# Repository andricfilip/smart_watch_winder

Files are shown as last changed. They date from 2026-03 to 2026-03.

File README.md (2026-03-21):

# Watch Winder - Full Project Guide

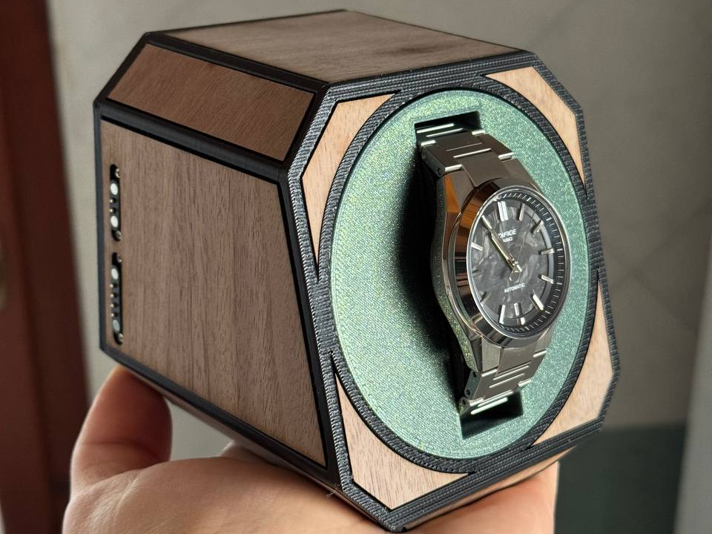
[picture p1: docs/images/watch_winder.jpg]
Watch Winder


This repository contains the complete watch-winder solution:

1. ESP8266 firmware for one watch (`winder/winder.ino`)
2. ESP8266 firmware for two watches (`doubleWinder/doubleWinder.ino`)
3. Raspberry Pi web dashboard (`pi-dashboard/`)
4. Modern React dashboard (`pi-dashboard-modern/`)
5. Assembly docs (SR + EN) in `docs/`

The firmware is API-only (no embedded HTML UI), and the dashboard controls the device over HTTP.

## 1) Project Structure

- `winder/winder.ino` - single watch firmware
- `doubleWinder/doubleWinder.ino` - double watch firmware
- `pi-dashboard/index.html` - dashboard UI
- `pi-dashboard/app.js` - dashboard logic and API calls
- `pi-dashboard/style.css` - dashboard style
- `pi-dashboard/docker-compose.yml` - dashboard container deploy
- `pi-dashboard-modern/` - modern React + Vite dashboard
- `docs/ASSEMBLY_GUIDE_SR.md` - assembly guide in Serbian
- `docs/ASSEMBLY_GUIDE_EN.md` - assembly guide in English
- `docs/images/` - wiring images used in docs
- `docs/images/watch_winder.jpg` - project preview image

## Assembly Guides

- Serbian: [docs/ASSEMBLY_GUIDE_SR.md](docs/ASSEMBLY_GUIDE_SR.md)
- English: [docs/ASSEMBLY_GUIDE_EN.md](docs/ASSEMBLY_GUIDE_EN.md)

## 2) How The System Works

1. ESP8266 runs motor control and exposes HTTP API.
2. Raspberry Pi hosts the dashboard.
3. Browser dashboard sends commands directly to ESP8266 API.
4. Internet is not required.
5. Local network path between browser and ESP8266 is required.

## 3) Choose Firmware (Single vs Double)

Flash only one firmware on one ESP8266 board:

- Use `winder/winder.ino` for one watch.
- Use `doubleWinder/doubleWinder.ino` for two watches.

## 4) Firmware Configuration (Required)

Before flashing, edit these constants in the selected `.ino` file:

- `STA_SSID`
- `STA_PASSWORD`
- `ENABLE_AP_FALLBACK`
- `AP_SSID`
- `AP_PASSWORD`
- `STA_CONNECT_TIMEOUT_MS`

Recommended values:

- `ENABLE_AP_FALLBACK = true` while testing
- `AP_PASSWORD` at least 12 characters
- `STA_CONNECT_TIMEOUT_MS = 10000` to `20000`

What they mean:

- `STA_*` = your home/local Wi-Fi credentials
- `ENABLE_AP_FALLBACK`:
  - `true` -> if STA connection fails, ESP starts fallback AP
  - `false` -> no AP fallback, ESP stays without network if STA fails
- `AP_*` = fallback network name/password

## 5) Runtime Config Parameters (TPD Engine)

The firmware now uses a time-based TPD scheduler instead of fixed `giri/delay` loops.

### Core parameters

- `targetTPD` range: `500-1000` (hard cap)
- `direction`: `CW`, `CCW`, `BIDIR`
- `mode`: `STANDARD`, `SMART`
- `speed` range: `1-5`
- `activeHours`: `[startHour, endHour]` (0-23)
- `runMinutes` range: `0-1440`

### Optional quiet profile

- `quietMode`: `true/false`
- `quietStartHour`, `quietEndHour`
- `nightSpeedCap`

Timer behavior:

- `runMinutes = 0` -> unlimited run time
- `runMinutes > 0` -> auto-stop after timer expires

## 6) API Endpoints

Available in both firmware variants:

- `GET /api/status`
- `GET /api/stats`
- `GET /api/health`
- `POST /api/config`
- `POST /api/start`
- `POST /api/stop`

Notes:

- Config write is POST-only.
- `POST /api/stop` is fail-safe and immediately releases motor outputs.
- Legacy `giri/delay` keys are still accepted for backward compatibility.

### Example `/api/config` payload

```json
{
  "targetTPD": 650,
  "direction": "BIDIR",
  "mode": "SMART",
  "speed": 3,
  "activeHours": [8, 23],
  "runMinutes": 0,
  "quietMode": true,
  "quietStartHour": 22,
  "quietEndHour": 7,
  "nightSpeedCap": 2
}
```

## 7) EEPROM Safety

Both firmware variants use protected config storage:

- magic
- version
- CRC

This prevents invalid config loads when format changes or EEPROM data is corrupted.

## 8) Stability Enhancements In Firmware

Both firmware variants include:

- non-blocking `millis()` scheduler (Wi-Fi friendly)
- rolling 24h progress tracking with hourly drift correction
- adaptive burst/pause distribution based on drift percent
- soft start/stop step ramp to reduce vibration/noise
- state machine: `IDLE`, `RUNNING`, `PAUSED`, `ERROR`, `TIMER_DONE`
- robust persistence with versioned records, CRC, and dual-slot write strategy
- periodic runtime snapshot for power-loss recovery

New runtime metrics exposed via API:

- `rotationsToday`
- `rotationsLastHour`
- `currentTPD`
- `driftPercent`
- `currentTPDProgress`
- `remainingRotations`
- `errorCode`

## 9) Flashing ESP8266

Use Arduino IDE or PlatformIO.

Basic Arduino IDE flow:

1. Open selected `.ino`.
2. Select correct ESP8266 board and COM port.
3. Install required libraries if missing (`ESP8266WiFi`, `ESP8266WebServer`, `EEPROM`).
4. Verify/Compile.
5. Upload.
6. Open Serial Monitor (115200) and read assigned IP.

## 10) Dashboard Setup On Raspberry Pi

### Option A - Simple static server

```bash
cd pi-dashboard
python3 -m http.server 8080
```

Open:

- Local Pi browser: `http://localhost:8080`
- Other LAN devices: `http://<IP_RASPBERRY_PI>:8080`

### Option B - Docker

```bash
cd pi-dashboard
docker compose up -d --build
```

Open from LAN devices:

- `http://<IP_RASPBERRY_PI>:8080`

Stop:

```bash
docker compose down
```

## 11) Dashboard First Start

1. Open dashboard.
2. Enter ESP URL (default example: `http://192.168.1.111`).
3. Choose mode:
   - `Single winder (1 sat)`
   - `Double winder (2 sata)`
4. Save device.
5. Click `Osvezi status`.
6. Configure values.
7. Click `Start`.
8. Use `Stop` when needed.

## 12) Network Scenarios

### Scenario A: Home Wi-Fi works

- ESP connects as STA.
- Dashboard (Pi/phone/laptop) reaches ESP via local IP.

### Scenario B: Home Wi-Fi fails + fallback enabled

- ESP starts fallback AP.
- Connect client device to AP.
- Dashboard works over fallback AP network.

### Scenario C: Home Wi-Fi fails + fallback disabled

- ESP is unreachable over network.
- Dashboard UI opens, but API calls fail.

## 13) Security Notes

- Keep strong `AP_PASSWORD` if fallback is enabled.
- Do not expose dashboard to internet unless you add auth/reverse proxy hardening.
- If you want LAN-only access, do not configure router port forwarding for `8080`.

## 14) Quick Troubleshooting

If dashboard shows offline / fetch errors:

1. Verify ESP and dashboard client are on reachable networks.
2. Confirm ESP IP in dashboard URL field.
3. Open `http://<ESP_IP>/api/status` directly from browser.
4. Check Serial Monitor for STA success/failure and fallback AP startup.
5. If browser cached old URL, save the new URL in dashboard again.

## 15) Recommended Production Profile

1. Validate stable STA connection for several reboots.
2. Keep fallback AP enabled only if you need service recovery.
3. Set sensible timer and speed values for your watch movement.
4. Periodically inspect `cyclesCompleted` and `lastStopReason` from `/api/status`.

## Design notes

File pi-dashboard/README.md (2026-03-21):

# Kontrola navijanja automatskog sata

Ovaj projekat ima dva firmware fajla i jedan dashboard:

1. `winder/winder.ino` za jedan sat.
2. `doubleWinder/doubleWinder.ino` za dva sata.
3. `pi-dashboard/` web panel za upravljanje i telemetriju.

## API endpointi

- `GET /api/status`
- `GET /api/stats`
- `GET /api/health`
- `POST /api/config`
- `POST /api/start`
- `POST /api/stop`

## Sta da menjas u firmware fajlovima

U oba fajla menjas iste mrezne konstante na vrhu:

1. `STA_SSID`: naziv tvoje kućne Wi-Fi mreze.
2. `STA_PASSWORD`: lozinka tvoje kućne mreze.
3. `ENABLE_AP_FALLBACK`: `true` ili `false`.
4. `AP_SSID`: naziv fallback AP mreze.
5. `AP_PASSWORD`: lozinka fallback AP mreze.
6. `STA_CONNECT_TIMEOUT_MS`: vreme cekanja konekcije na Wi-Fi.

Preporucene vrednosti:

1. `ENABLE_AP_FALLBACK = true` dok testiras.
2. `AP_PASSWORD` promeni u jaku lozinku od bar 12 karaktera.
3. `STA_CONNECT_TIMEOUT_MS = 10000` do `20000`.

## Razlika single i double firmware-a (TPD engine)

Single (`winder/winder.ino`) glavni parametri:

1. `targetTPD` opseg `500-1000`.
2. `direction`: `CW`, `CCW`, `BIDIR`.
3. `mode`: `STANDARD` ili `SMART`.
4. `speed` opseg `1-5`.
5. `activeHours`: `[startHour, endHour]`.
6. `runMinutes` opseg `0-1440`.

Double (`doubleWinder/doubleWinder.ino`) glavni parametri:

1. `targetTPD1`, `targetTPD2` opseg `500-1000`.
2. `direction1`, `direction2`.
3. `mode1`, `mode2`.
4. `speed1`, `speed2` opseg `1-5`.
5. `activeStartHour1/2`, `activeEndHour1/2`.
6. `runMinutes` opseg `0-1440`.

Napomena:

1. Legacy polja (`giri`, `delay`, `giri1`, `giri2`, `gdelay`) su i dalje podrzana radi kompatibilnosti.
2. Dashboard sada salje nova TPD polja kao JSON.

## Podrazumevano ponasanje tajmera

1. `runMinutes = 0` znaci rad bez vremenskog limita.
2. `POST /api/start` pokrece sistem.
3. Ako je `runMinutes > 0`, sistem se sam zaustavlja po isteku vremena.
4. `POST /api/stop` odmah zaustavlja sve motore (fail-safe stop).

## Nova telemetrija u statusu

`/api/status`, `/api/stats` i `/api/health` sada vracaju dodatne metrike:

1. `rotationsToday`
2. `rotationsLastHour`
3. `currentTPD`
4. `driftPercent`
5. `currentTPDProgress`
6. `remainingRotations`
7. `motorState`
8. `errorCode`
9. `uptime`

## Pokretanje dashboard-a

Lokalno na Raspberry Pi:

```bash
cd pi-dashboard
python3 -m http.server 8080
```

Dashboard URL:

```text
http://localhost:8080
```

## Docker deploy za lokalnu mrezu

```bash
cd pi-dashboard
docker compose up -d --build
```

Otvaranje sa drugih uredjaja u istoj mrezi:

```text
http://IP_RASPBERRY_PI:8080
```

Gasenje:

```bash
docker compose down
```

Napomena:

1. Nemoj raditi port forwarding na ruteru za port `8080` ako zelis samo LAN pristup.
2. Dashboard podrazumevano koristi URL `http://192.168.1.111`, ali ga mozes promeniti u panelu.

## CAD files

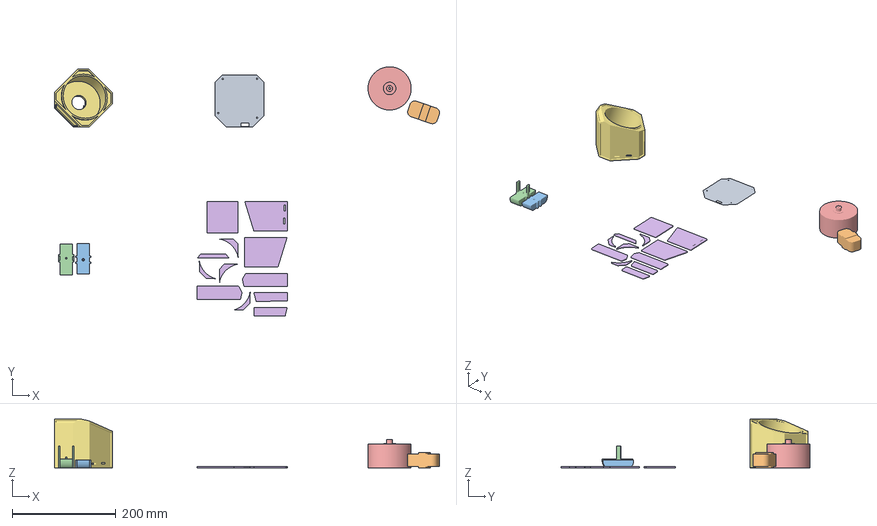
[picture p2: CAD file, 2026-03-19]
print_profile/BackSmall.3mf
743.3 x 481.3 x 94.5 mm
BackSmall.stl
RotorSmall.stl_2
WatchHolderV2.stl
Sub-merged body
RotorSmall.stl
BodyPanels.stl
BodySmall.stl

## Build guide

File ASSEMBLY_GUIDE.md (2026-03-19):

# Assembly Guide Index

Assembly documentation has been moved to the docs folder.

- Serbian version: [docs/ASSEMBLY_GUIDE_SR.md](docs/ASSEMBLY_GUIDE_SR.md)
- English version: [docs/ASSEMBLY_GUIDE_EN.md](docs/ASSEMBLY_GUIDE_EN.md)

Wiring images used by both guides:

- [docs/images/single-wiring.png](docs/images/single-wiring.png)
- [docs/images/double-wiring.png](docs/images/double-wiring.png)

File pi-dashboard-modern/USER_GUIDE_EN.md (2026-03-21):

# Application User Guide (Modern Dashboard)

This is a practical guide: what to configure, which values to use, and what result you get on your watch winder.

## 1. What this app does

The app controls ESP8266 firmware over local network.

Supported:

1. start and stop winding
2. TPD-based configuration
3. direction and mode selection
4. runtime and health telemetry

## 2. Quick start (3 minutes)

1. Make sure firmware is uploaded to ESP:
   - single: `winder/winder.ino`
   - double: `doubleWinder/doubleWinder.ino`
2. Start dashboard:
   - `cd pi-dashboard-modern`
   - `docker compose up --build -d`
3. Open in browser: `http://IP_RPI:8090` (or `http://localhost:8090` on Raspberry Pi)
4. Click `Refresh`.
5. Set parameters and click `Save settings`.
6. Click `Start`.

If status is `Offline`, verify ESP and dashboard are on same network and device URL is correct.

## 3. Parameters and expected behavior

## targetTPD (500-1000)

Meaning:

- number of target rotations in 24h

Effect:

- higher TPD = more frequent activity and more total rotations
- lower TPD = less frequent activity and quieter operation

Recommendation:

- start with `650`, then fine tune for your watch

## direction (CW / CCW / BIDIR)

Meaning:

- winding direction

Effect:

- `CW`: clockwise only
- `CCW`: counterclockwise only
- `BIDIR`: alternating direction (safe default if watch requirement is unknown)

## mode (STANDARD / SMART)

Meaning:

- cycle distribution strategy

Effect:

- `STANDARD`: regular distribution through the day
- `SMART`: adaptive balancing of winding cycles

## speed (1-5)

Meaning:

- stepper speed level

Effect:

- `1-2`: quieter and smoother
- `4-5`: faster execution, potentially more noise

Recommendation:

- use `2` or `3` for stable and quiet behavior

## activeHours

Meaning:

- time window when winding is allowed

Effect:

- outside this range, system pauses

Example:

- `8-23`: active during day/evening, idle at night

## smartSwitchRotations

Meaning:

- in SMART mode, direction switch interval in rotations

Effect:

- higher value = less frequent direction changes
- lower value = more frequent direction changes

## quietMode + quietStartHour + quietEndHour + nightSpeedCap

Meaning:

- quieter night profile

Effect:

- in quiet hours speed is limited by `nightSpeedCap`
- less noise during night

Example:

- quiet from `22` to `7`, cap `2`

## runMinutes

Meaning:

- max runtime before auto-stop

Effect:

- `0` = no time limit
- `>0` = auto-stop after configured duration

## 4. Status panel metrics

1. `State`: current state (`IDLE`, `RUNNING`, `PAUSED`, `ERROR`, `TIMER_DONE`)
2. `Error`: error code if present
3. `Timer`: remaining timer time
4. `Network`: network mode and IP
5. `Rot today`: total rotations today
6. `Rot hour`: rotations in last hour
7. `Current TPD`: projected current TPD pace
8. `Drift %`: deviation from planned daily pace
9. `Progress`: completion percent for daily target
10. `Remaining`: rotations left to target
11. `Heap`: free ESP memory
12. `Uptime`: device uptime

## 5. Recommended starting values

### Single

1. targetTPD: `650`
2. direction: `BIDIR`
3. mode: `STANDARD`
4. speed: `2`
5. activeHours: `0-23`
6. quietMode: `true`
7. quiet: `22-7`, cap `2`

### Double

1. targetTPD1/2: `650`
2. direction1/2: `BIDIR`
3. mode1/2: `STANDARD`
4. speed1/2: `2`
5. active hours for both heads: `0-23`
6. quietMode: `true`

## 6. Single vs Double

1. If firmware is single, use single settings.
2. If firmware is double, use double settings.
3. If mode lock is enabled via Docker env, app mode cannot be changed from UI.

## 7. Common situations and fixes

## Offline

1. Check `APP_DEFAULT_DEVICE_URL` in `docker-compose.yml`.
2. Verify ESP responds to `GET /api/status` from browser.
3. Confirm ESP and dashboard are on same LAN.

## Motor is too noisy

1. lower `speed` to `2`
2. enable `quietMode`
3. set `nightSpeedCap` to `1` or `2`

## Watch seems under-wound

1. increase `targetTPD` in +50 steps
2. monitor `Drift %` and `Remaining`

## 8. Docker startup config (important)

In `pi-dashboard-modern/docker-compose.yml` use:

1. `APP_DEVICE_MODE`: `single` or `double`
2. `APP_LOCK_DEVICE_MODE`: lock mode in UI
3. `APP_DEFAULT_DEVICE_URL`: ESP IP address
4. `APP_LOCK_DEVICE_URL`: lock URL field
5. `APP_LANGUAGE`: `sr` or `en`
6. `APP_LOCK_LANGUAGE`: lock language selection

After changing env values, run:

1. `docker compose up --build -d`

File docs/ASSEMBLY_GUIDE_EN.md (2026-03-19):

# Watch Winder Assembly Guide

This is a compact watch winder build with wooden slots (3D printable panels) and optional Pogo pin contacts for a modular second winder.

## 1. Quick Overview

The system uses:

1. D1 Mini (ESP8266)
2. 28BYJ-48 stepper + ULN2003 driver
3. Bearings and 3D printed parts
4. Optional Pogo pins for the second modular motor

If the motor does not rotate correctly (vibration, stuttering, unstable direction), the 4 signal wires between D1 Mini and ULN2003 may require a different order depending on motor batch. Reorder the 4 signal wires until rotation is smooth.

## 2. Bill of Materials (BOM)

1. Pogo pins (4P + 2P pair)
   https://s.click.aliexpress.com/e/_c2xJoAxh
2. D1 Mini microcontroller
   https://s.click.aliexpress.com/e/_c2yz2bsB
3. Stepper motor + ULN2003 driver (one set per winder)
   https://s.click.aliexpress.com/e/_c3bp08OR
4. 6001ZZ bearings
   https://s.click.aliexpress.com/e/_c3FSeHun

Notes:

- Single variant needs 1x motor + driver.
- Double variant needs 2x motor + driver.
- Pogo pins are optional, but recommended for modular second-winder contacts.

## 3. Wiring Diagrams (Single and Double)

### Single winder wiring

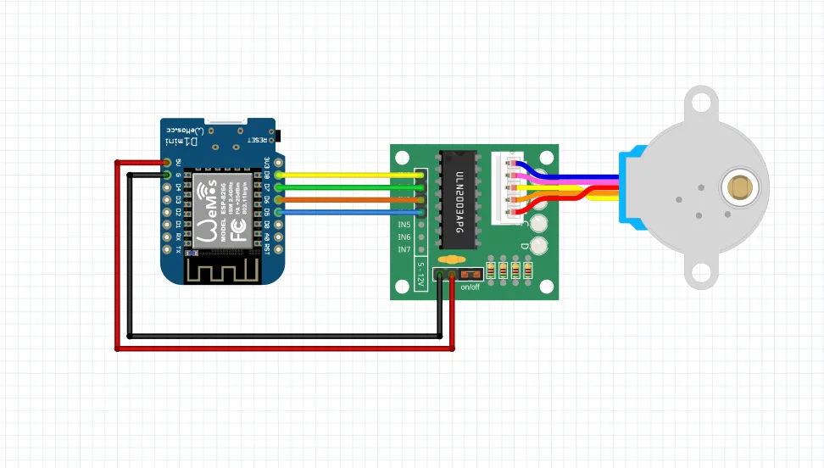
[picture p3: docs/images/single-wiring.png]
Single winder wiring


### Double winder wiring

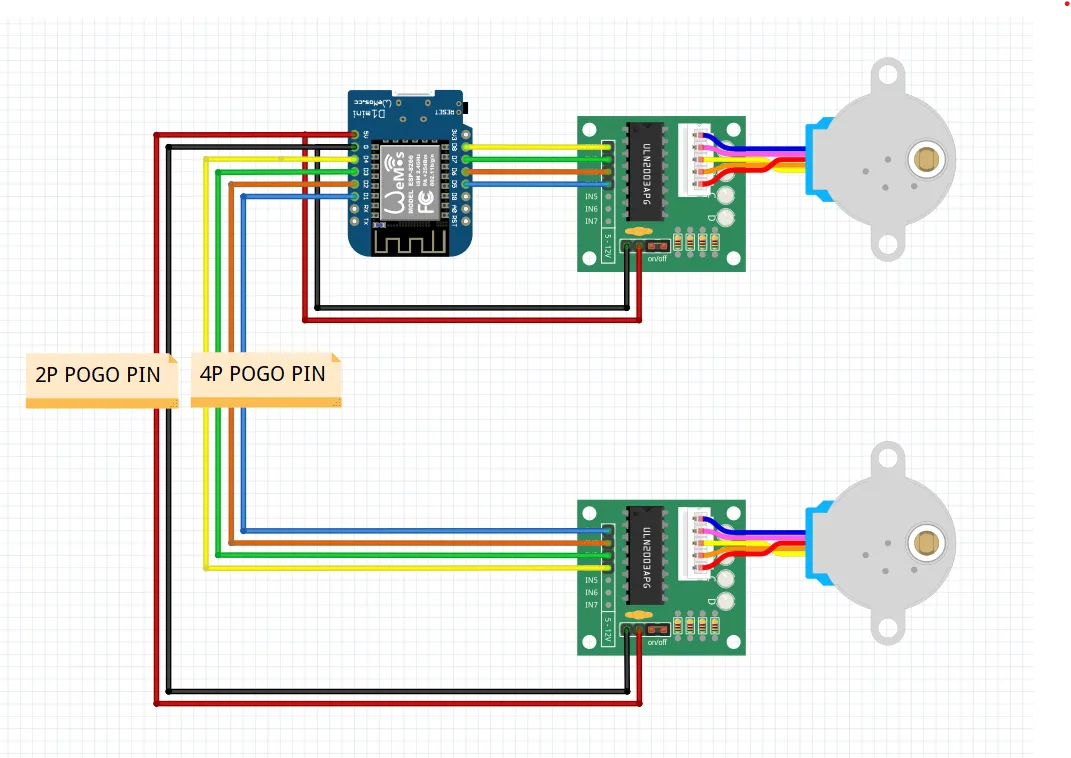
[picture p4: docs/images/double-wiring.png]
Double winder wiring


## 4. Pin Mapping (Firmware)

### Single firmware

File: `winder/winder.ino`

- `IN1 = D5`
- `IN2 = D6`
- `IN3 = D7`
- `IN4 = D8`

### Double firmware

File: `doubleWinder/doubleWinder.ino`

Motor A:

- `IN1_A = D5`
- `IN2_A = D6`
- `IN3_A = D7`
- `IN4_A = D8`

Motor B:

- `IN1_B = D4`
- `IN2_B = D3`
- `IN3_B = D2`
- `IN4_B = D1`

## 5. Step-by-Step Assembly

1. Assemble the mechanical structure and install 6001ZZ bearings.
2. Mount D1 Mini and ULN2003 driver board(s).
3. Connect shared power and GND for all modules.
4. Connect D1 Mini signal wires to ULN2003 according to pin map.
5. Connect the stepper cable to ULN2003.
6. For double variant, wire the second driver/motor pair.
7. If using Pogo pins, verify both 4P (signal) and 2P (power/GND) contact quality.
8. Before closing the case, test rotation at low speed.

## 6. Firmware Selection and Upload

1. For one watch, upload `winder/winder.ino`.
2. For two watches, upload `doubleWinder/doubleWinder.ino`.

Before uploading, configure network constants in firmware:

- `STA_SSID`
- `STA_PASSWORD`
- `ENABLE_AP_FALLBACK`
- `AP_SSID`
- `AP_PASSWORD`
- `STA_CONNECT_TIMEOUT_MS`

Recommended settings:

1. Keep `ENABLE_AP_FALLBACK = true` during initial testing.
2. Use a strong `AP_PASSWORD` (12+ chars).
3. Set `STA_CONNECT_TIMEOUT_MS` to 10000-20000.

## 7. First Boot and Validation

1. Upload firmware.
2. Open Serial Monitor at 115200 and read the assigned IP.
3. Start dashboard from folder `pi-dashboard`.
4. In dashboard, set device URL and click Save Device.
5. Click Refresh Status.
6. Configure parameters and click Start.
7. Verify direction and smooth rotation.

## 8. Dashboard and Timer

- `runMinutes = 0`: unlimited run.
- `runMinutes > 0`: automatic stop when timer expires.
- `Stop` is fail-safe and immediately releases the motor.

## 9. Recommended Starting Setup

Single:

1. `giri = 3`
2. `speed = 2`
3. `delay = 7`

Double:

1. `giri1 = 3`, `speed1 = 2`
2. `giri2 = 3`, `speed2 = 2`
3. `gdelay = 7`

Then fine-tune values based on watch weight and mechanical fit.

## 10. Troubleshooting

1. Motor does not start:
   - check power and shared GND
   - check motor connector on ULN2003
2. Motor vibrates but does not rotate:
   - reorder the 4 signal wires
3. Dashboard reports offline:
   - confirm IP and make sure ESP and dashboard are on same LAN
4. Second motor not working in double mode:
   - verify Motor B pin mapping
   - inspect 2P/4P Pogo contacts

## 11. Video References

Add links to your published videos:

- Part 1: <INSERT_LINK>
- Part 2: <INSERT_LINK>
- Final version: <INSERT_LINK>

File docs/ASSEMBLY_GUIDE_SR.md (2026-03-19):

# Watch Winder Uputstvo za Sklapanje

Elegant watch winder sa drvenim slotovima (3D printable paneli).
Ovo je novi, kompaktniji model sa opcijom Pogo pin kontakata za drugi winder.

## 1. Kratak pregled

Sistem koristi:

1. D1 Mini (ESP8266)
2. 28BYJ-48 stepper + ULN2003 driver
3. lezajeve i 3D print delove
4. opciono Pogo pinove za modularni drugi motor

Ako motor ne radi pravilno (vibrira, preskace, menja smer cudno), redosled 4 signalna voda izmedju D1 Mini i ULN2003 moze da varira u zavisnosti od motora. Menjaj redosled dok ne dobijes stabilnu rotaciju.

## 2. Materijal (BOM)

1. Pogo pins (4P + 2P par)
   https://s.click.aliexpress.com/e/_c2xJoAxh
2. D1 Mini microcontroller
   https://s.click.aliexpress.com/e/_c2yz2bsB
3. Stepper motor + ULN2003 driver (za svaki winder po 1 set)
   https://s.click.aliexpress.com/e/_c3bp08OR
4. 6001ZZ bearings
   https://s.click.aliexpress.com/e/_c3FSeHun

Napomena:

- Za single varijantu treba 1x motor+driver.
- Za double varijantu trebaju 2x motor+driver.
- Pogo pinovi su opcioni, ali preporuceni za modularni drugi winder.

## 3. Vizuelno povezivanje (single i double)

### Single winder wiring

Single winder wiring

### Double winder wiring

Double winder wiring

## 4. Pin mapping (firmware)

### Single firmware

Fajl: `winder/winder.ino`

- `IN1 = D5`
- `IN2 = D6`
- `IN3 = D7`
- `IN4 = D8`

### Double firmware

Fajl: `doubleWinder/doubleWinder.ino`

Motor A:

- `IN1_A = D5`
- `IN2_A = D6`
- `IN3_A = D7`
- `IN4_A = D8`

Motor B:

- `IN1_B = D4`
- `IN2_B = D3`
- `IN3_B = D2`
- `IN4_B = D1`

## 5. Korak-po-korak sklapanje

1. Sastavi mehanicki deo i ubaci 6001ZZ lezajeve.
2. Montiraj D1 Mini i ULN2003 driver(e) na nosace.
3. Povezi napajanje i GND zajednicki za sve module.
4. Povezi signalne vodove sa D1 Mini na ULN2003 prema pin mapiranju.
5. Povezi stepper konektor na ULN2003.
6. Ako koristis double varijantu, povezi i drugi driver.
7. Ako koristis Pogo pinove, proveri kontakt 4P (signal) i 2P (napajanje/GND).
8. Pre prvog zatvaranja kucista testiraj rotaciju sa malom brzinom.

## 6. Firmware izbor i upload

1. Za 1 sat upload `winder/winder.ino`.
2. Za 2 sata upload `doubleWinder/doubleWinder.ino`.

Pre upload-a podesi mrezu u firmware-u:

- `STA_SSID`
- `STA_PASSWORD`
- `ENABLE_AP_FALLBACK`
- `AP_SSID`
- `AP_PASSWORD`
- `STA_CONNECT_TIMEOUT_MS`

Preporuka:

1. Drzi `ENABLE_AP_FALLBACK = true` dok testiras.
2. Koristi jaku `AP_PASSWORD` lozinku (12+ karaktera).
3. `STA_CONNECT_TIMEOUT_MS` stavi 10000-20000.

## 7. Prvo pokretanje i test

1. Uploadaj firmware.
2. Otvori Serial Monitor na 115200 i procitaj IP adresu.
3. Pokreni dashboard iz foldera `pi-dashboard`.
4. U dashboard unesi URL uredjaja i klikni `Sacuvaj uredjaj`.
5. Klikni `Osvezi status`.
6. Podesi parametre i `Start`.
7. Proveri smer i stabilnost okretanja.

## 8. Dashboard i tajmer

- `runMinutes = 0`: bez limita rada.
- `runMinutes > 0`: automatski stop po isteku vremena.
- `Stop` je fail-safe i odmah otpusta motor.

## 9. Recommended starting setup

Single:

1. `giri = 3`
2. `speed = 2`
3. `delay = 7`

Double:

1. `giri1 = 3`, `speed1 = 2`
2. `giri2 = 3`, `speed2 = 2`
3. `gdelay = 7`

Zatim fino podesi u odnosu na sat i mehaniku nosaca.

## 10. Troubleshooting

1. Motor ne krece:
   - proveri napajanje i GND
   - proveri konektor motora na ULN2003
2. Motor vibrira bez rotacije:
   - promeni redosled 4 signalna voda
3. Dashboard je offline:
   - proveri IP i da su ESP i dashboard u istoj mrezi
4. Double ne radi na drugom motoru:
   - proveri pin mapiranje za Motor B
   - proveri 2P/4P Pogo kontakte

## 11. Video reference

Dodaj linkove ka svojim objavama:

- Part 1: <INSERT_LINK>
- Part 2: <INSERT_LINK>
- Final version: <INSERT_LINK>

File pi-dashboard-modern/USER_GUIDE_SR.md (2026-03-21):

# Uputstvo za koriscenje aplikacije (Modern Dashboard)

Ovo je prakticno uputstvo: sta da podesis, koje vrednosti da uneses i kakav rezultat dobijas na watch winder uredjaju.

## 1. Sta aplikacija radi

Aplikacija upravlja ESP8266 firmware-om preko lokalne mreze.

Podrzano:

1. pokretanje i zaustavljanje navijanja
2. podesavanje TPD logike
3. izbor smera i rezima rada
4. pracenje metrike rada i zdravlja sistema

## 2. Brzi start (3 minuta)

1. Uveri se da je firmware uploadovan na ESP:
   - single: `winder/winder.ino`
   - double: `doubleWinder/doubleWinder.ino`
2. Pokreni dashboard:
   - `cd pi-dashboard-modern`
   - `docker compose up --build -d`
3. Otvori u browser-u: `http://IP_RPI:8090` (ili `http://localhost:8090` na samom Pi)
4. Klikni `Osvezi`.
5. Podesi parametre i klikni `Sacuvaj podesavanja`.
6. Klikni `Start`.

Ako je status `Van mreze`, proveri da su ESP i dashboard u istoj mrezi i da je URL tacan.

## 3. Parametri i sta dobijas

## targetTPD (500-1000)

Znacenje:

- broj rotacija koje zelis u okviru 24h

Efekat:

- veci TPD = cesce aktiviranje i vise ukupnih rotacija
- manji TPD = redje aktiviranje i mirniji rad

Preporuka:

- kreni sa `650`, pa fino podesi po ponasanju sata

## direction (CW / CCW / BIDIR)

Znacenje:

- smer navijanja

Efekat:

- `CW`: samo u smeru kazaljke
- `CCW`: samo suprotno
- `BIDIR`: naizmenicno, bezbedan izbor ako nisi siguran koji smer sat trazi

## mode (STANDARD / SMART)

Znacenje:

- nacin raspodele ciklusa

Efekat:

- `STANDARD`: regularna raspodela kroz dan
- `SMART`: inteligentnije menjanje i balansiranje ciklusa

## speed (1-5)

Znacenje:

- brzina step motora

Efekat:

- `1-2`: tisi i mirniji rad
- `4-5`: brze izvrsenje, potencijalno vise buke

Preporuka:

- koristi `2` ili `3` za stabilan i tih rad

## activeHours

Znacenje:

- satnica kada je dozvoljen aktivan rad

Efekat:

- van tog intervala sistem pauzira

Primer:

- `8-23`: radi tokom dana/veceri, miruje nocu

## smartSwitchRotations

Znacenje:

- na koliko rotacija menja smer u SMART rezimu

Efekat:

- veca vrednost = redje menjanje smera
- manja vrednost = cesce menjanje smera

## quietMode + quietStartHour + quietEndHour + nightSpeedCap

Znacenje:

- nocni tisi profil

Efekat:

- u quiet periodu brzina se limitira na `nightSpeedCap`
- manje buke nocu

Primer:

- quiet od `22` do `7`, cap `2`

## runMinutes

Znacenje:

- koliko dugo da sistem radi pre auto-stop

Efekat:

- `0` = bez limita
- `>0` = automatski stop nakon zadatog vremena

## 4. Status panel (sta znaci svaka metrika)

1. `State`: trenutno stanje (`IDLE`, `RUNNING`, `PAUSED`, `ERROR`, `TIMER_DONE`)
2. `Error`: kod greske (ako postoji)
3. `Timer`: preostalo vreme timera
4. `Network`: mrezni mod i IP
5. `Rot today`: ukupne rotacije danas
6. `Rot hour`: rotacije u poslednjem satu
7. `Current TPD`: projekcija trenutnog TPD tempa
8. `Drift %`: odstupanje od planiranog dnevnog tempa
9. `Progress`: procenat ispunjenog dnevnog plana
10. `Remaining`: preostale rotacije do cilja
11. `Heap`: slobodna memorija na ESP-u
12. `Uptime`: vreme rada uredjaja

## 5. Preporucene pocetne vrednosti

### Single

1. targetTPD: `650`
2. direction: `BIDIR`
3. mode: `STANDARD`
4. speed: `2`
5. activeHours: `0-23`
6. quietMode: `true`
7. quiet: `22-7`, cap `2`

### Double

1. targetTPD1/2: `650`
2. direction1/2: `BIDIR`
3. mode1/2: `STANDARD`
4. speed1/2: `2`
5. active hours obe glave: `0-23`
6. quietMode: `true`

## 6. Single vs Double

1. Ako je firmware single, koristi single podešavanja.
2. Ako je firmware double, koristi double podešavanja.
3. Ne treba menjati mod u aplikaciji ako je lock ukljucen kroz Docker env.

## 7. Ceste situacije i resenja

## Van mreze

1. Proveri `APP_DEFAULT_DEVICE_URL` u `docker-compose.yml`.
2. Proveri da ESP vraca `GET /api/status` iz browser-a.
3. Proveri da su uredjaji u istoj LAN mrezi.

## Motor radi preglasno

1. spusti `speed` na `2`
2. ukljuci `quietMode`
3. smanji `nightSpeedCap` na `1` ili `2`

## Sat deluje da je premalo navijan

1. povecaj `targetTPD` u koracima po 50
2. proveri `Drift %` i `Remaining`

## 8. Docker konfiguracija (najvaznije)

U `pi-dashboard-modern/docker-compose.yml` koristis:

1. `APP_DEVICE_MODE`: `single` ili `double`
2. `APP_LOCK_DEVICE_MODE`: zakljucava mod u UI
3. `APP_DEFAULT_DEVICE_URL`: IP ESP uredjaja
4. `APP_LOCK_DEVICE_URL`: zakljucava URL polje
5. `APP_LANGUAGE`: `sr` ili `en`
6. `APP_LOCK_LANGUAGE`: zakljucava izbor jezika

Posle izmene env vrednosti uradi:

1. `docker compose up --build -d`

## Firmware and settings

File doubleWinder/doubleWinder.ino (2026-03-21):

#include <Arduino.h>
#include <ESP8266WiFi.h>
#include <ESP8266WebServer.h>
#include <EEPROM.h>
#include <string.h>

// ===== NETWORK SETTINGS =====
const char* STA_SSID = "YOUR_WIFI_SSID";
const char* STA_PASSWORD = "YOUR_WIFI_PASSWORD";
const bool ENABLE_AP_FALLBACK = true;
const char* AP_SSID = "WatchWinder-Setup";
const char* AP_PASSWORD = "ChangeMe123!";
const unsigned long STA_CONNECT_TIMEOUT_MS = 15000;

// ===== PINS =====
const int IN1_A = D5;
const int IN2_A = D6;
const int IN3_A = D7;
const int IN4_A = D8;

const int IN1_B = D4;
const int IN2_B = D3;
const int IN3_B = D2;
const int IN4_B = D1;

const int motorPins1[4] = {IN1_A, IN2_A, IN3_A, IN4_A};
const int motorPins2[4] = {IN1_B, IN2_B, IN3_B, IN4_B};

// ===== MOTOR & SCHEDULER =====
const int STEPS_PER_REV = 2048;
const unsigned long DAY_MS = 86400000UL;
const unsigned long HOUR_MS = 3600000UL;
const unsigned long MIN_PAUSE_MS = 5UL * 60000UL;
const unsigned long MAX_PAUSE_MS = 10UL * 60000UL;
const unsigned long MIN_BURST_MS = 1UL * 60000UL;
const unsigned long MAX_BURST_MS = 3UL * 60000UL;
const unsigned long JAM_TIMEOUT_MS = 12000UL;
const unsigned long RUNTIME_PERSIST_MS = 15UL * 60000UL;
const int MIN_EFFECTIVE_STEP_DELAY_MS = 3;
const bool HAS_CURRENT_SENSOR = false;
const int CURRENT_SENSOR_PIN = A0;
const int CURRENT_JAM_THRESHOLD = 980;

enum DirectionMode { DIR_CW = 0, DIR_CCW = 1, DIR_BIDIR = 2 };
enum WinderMode { MODE_STANDARD = 0, MODE_SMART = 1 };
enum SystemState { SYS_IDLE = 0, SYS_RUNNING = 1, SYS_PAUSED = 2, SYS_ERROR = 3, SYS_TIMER_DONE = 4 };
enum ErrorCode {
  ERR_NONE = 0,
  ERR_JAM_DETECTED = 1,
  ERR_OVERCURRENT = 2,
  ERR_TIMER_DONE = 3,
  ERR_INVALID_CONFIG = 4
};
enum LogLevel { LOG_ERROR = 0, LOG_INFO = 1, LOG_DEBUG = 2 };

const char* stateToText(SystemState s) {
  switch (s) {
    case SYS_IDLE:
      return "IDLE";
    case SYS_RUNNING:
      return "RUNNING";
    case SYS_PAUSED:
      return "PAUSED";
    case SYS_ERROR:
      return "ERROR";
    case SYS_TIMER_DONE:
      return "TIMER_DONE";
    default:
      return "UNKNOWN";
  }
}

const char* errorToText(ErrorCode e) {
  switch (e) {
    case ERR_NONE:
      return "NONE";
    case ERR_JAM_DETECTED:
      return "JAM_DETECTED";
    case ERR_OVERCURRENT:
      return "OVERCURRENT";
    case ERR_TIMER_DONE:
      return "TIMER_DONE";
    case ERR_INVALID_CONFIG:
      return "INVALID_CONFIG";
    default:
      return "UNKNOWN";
  }
}

const char* directionToText(DirectionMode d) {
  switch (d) {
    case DIR_CW:
      return "CW";
    case DIR_CCW:
      return "CCW";
    default:
      return "BIDIR";
  }
}

const char* modeToText(WinderMode m) {
  return m == MODE_SMART ? "SMART" : "STANDARD";
}

DirectionMode parseDirection(String value) {
  value.trim();
  value.toUpperCase();
  if (value == "CW") return DIR_CW;
  if (value == "CCW") return DIR_CCW;
  return DIR_BIDIR;
}

WinderMode parseMode(String value) {
  value.trim();
  value.toUpperCase();
  if (value == "SMART") return MODE_SMART;
  return MODE_STANDARD;
}

struct MotorConfig {
  int targetTPD;
  int direction;
  int speed;
  int mode;
  int activeStartHour;
  int activeEndHour;
  int smartSwitchRotations;
};

struct Config {
  MotorConfig m1;
  MotorConfig m2;
  bool quietMode;
  int quietStartHour;
  int quietEndHour;
  int nightSpeedCap;
  int runMinutes;
  int logLevel;
  int legacyDelay;
};

struct RuntimeSnapshot {
  uint32_t stepsToday1;
  uint32_t stepsToday2;
  uint32_t totalSteps1;
  uint32_t totalSteps2;
  uint32_t dayElapsedMs;
  uint8_t hourCursor;
  uint32_t hourBuckets1[24];
  uint32_t hourBuckets2[24];
  uint32_t cycles1;
  uint32_t cycles2;
  uint16_t smartRotAcc1;
  uint16_t smartRotAcc2;
};

struct PersistRecord {
  uint32_t magic;
  uint16_t version;
  uint16_t valid;
  uint32_t seq;
  Config cfg;
  RuntimeSnapshot snap;
  uint32_t crc;
};

const uint32_t CONFIG_MAGIC = 0x57574E44;  // WWND
const uint16_t CONFIG_VERSION = 4;
const uint16_t RECORD_VALID = 0xA55A;

struct MotorRuntime {
  bool burstActive;
  bool burstDirectionCw;
  bool nextBidirCw;
  unsigned long pauseUntilMs;
  unsigned long burstStartMs;
  unsigned long burstTargetSteps;
  unsigned long burstStepsDone;
  unsigned long stepsToday;
  unsigned long totalSteps;
  unsigned long nextStepAtMs;
  unsigned long lastStepMs;
  unsigned long cyclesCompleted;
  int phaseIndex;
  unsigned int smartRotationAccumulator;
};

ESP8266WebServer server(80);

Config config;
Config lastSavedConfig;
bool hasLastSavedConfig = false;

MotorRuntime motor1, motor2;
bool usingApFallback = false;
bool systemEnabled = true;
bool timerActive = false;
unsigned long runUntilMs = 0;
String lastStopReason = "boot";
SystemState systemState = SYS_IDLE;
ErrorCode errorCode = ERR_NONE;
unsigned long dayStartMs = 0;
unsigned long lastPersistMs = 0;
unsigned long lastHourCheckMs = 0;
int hourCursor = 0;
uint32_t hourBuckets1[24];
uint32_t hourBuckets2[24];
int activeMotor = 1;
uint32_t persistSeq = 0;
int persistSlot = 0;

const int seq[8][4] = {
  {1, 0, 0, 0},
  {1, 1, 0, 0},
  {0, 1, 0, 0},
  {0, 1, 1, 0},
  {0, 0, 1, 0},
  {0, 0, 1, 1},
  {0, 0, 0, 1},
  {1, 0, 0, 1}
};

int clampInt(int value, int minVal, int maxVal) {
  if (value < minVal) return minVal;
  if (value > maxVal) return maxVal;
  return value;
}

void logMessage(LogLevel level, const String& msg) {
  if (level <= (LogLevel)config.logLevel) {
    Serial.println(msg);
  }
}

unsigned long crc32(const uint8_t* data, size_t len) {
  uint32_t crc = 0xFFFFFFFF;
  for (size_t i = 0; i < len; i++) {
    crc ^= data[i];
    for (uint8_t b = 0; b < 8; b++) {
      crc = (crc & 1) ? (crc >> 1) ^ 0xEDB88320 : crc >> 1;
    }
  }
  return ~crc;
}

void setDefaultMotorConfig(MotorConfig& mc) {
  mc.targetTPD = 650;
  mc.direction = DIR_BIDIR;
  mc.speed = 3;
  mc.mode = MODE_STANDARD;
  mc.activeStartHour = 0;
  mc.activeEndHour = 23;
  mc.smartSwitchRotations = 10;
}

void setDefaultConfig() {
  setDefaultMotorConfig(config.m1);
  setDefaultMotorConfig(config.m2);
  config.quietMode = true;
  config.quietStartHour = 22;
  config.quietEndHour = 7;
  config.nightSpeedCap = 2;
  config.runMinutes = 0;
  config.logLevel = LOG_INFO;
  config.legacyDelay = 10;
}

void sanitizeMotorConfig(MotorConfig& mc) {
  mc.targetTPD = clampInt(mc.targetTPD, 500, 1000);
  mc.direction = clampInt(mc.direction, DIR_CW, DIR_BIDIR);
  mc.speed = clampInt(mc.speed, 1, 5);
  mc.mode = clampInt(mc.mode, MODE_STANDARD, MODE_SMART);
  mc.activeStartHour = clampInt(mc.activeStartHour, 0, 23);
  mc.activeEndHour = clampInt(mc.activeEndHour, 0, 23);
  mc.smartSwitchRotations = clampInt(mc.smartSwitchRotations, 2, 100);
}

void sanitizeConfig() {
  sanitizeMotorConfig(config.m1);
  sanitizeMotorConfig(config.m2);
  config.quietStartHour = clampInt(config.quietStartHour, 0, 23);
  config.quietEndHour = clampInt(config.quietEndHour, 0, 23);
  config.nightSpeedCap = clampInt(config.nightSpeedCap, 1, 5);
  config.runMinutes = clampInt(config.runMinutes, 0, 1440);
  config.logLevel = clampInt(config.logLevel, LOG_ERROR, LOG_DEBUG);
  config.legacyDelay = clampInt(config.legacyDelay, 1, 60);
}

unsigned int recordSize() {
  return (unsigned int)sizeof(PersistRecord);
}

int slotAddress(int slot) {
  return slot * (int)recordSize();
}

void captureSnapshot(RuntimeSnapshot& snap, unsigned long now) {
  snap.stepsToday1 = motor1.stepsToday;
  snap.stepsToday2 = motor2.stepsToday;
  snap.totalSteps1 = motor1.totalSteps;
  snap.totalSteps2 = motor2.totalSteps;
  snap.dayElapsedMs = (uint32_t)(now - dayStartMs);
  snap.hourCursor = (uint8_t)hourCursor;
  for (int i = 0; i < 24; i++) {
    snap.hourBuckets1[i] = hourBuckets1[i];
    snap.hourBuckets2[i] = hourBuckets2[i];
  }
  snap.cycles1 = motor1.cyclesCompleted;
  snap.cycles2 = motor2.cyclesCompleted;
  snap.smartRotAcc1 = motor1.smartRotationAccumulator;
  snap.smartRotAcc2 = motor2.smartRotationAccumulator;
}

void applySnapshot(const RuntimeSnapshot& snap, unsigned long now) {
  dayStartMs = now - min((unsigned long)snap.dayElapsedMs, DAY_MS - 1UL);
  hourCursor = snap.hourCursor % 24;
  for (int i = 0; i < 24; i++) {
    hourBuckets1[i] = snap.hourBuckets1[i];
    hourBuckets2[i] = snap.hourBuckets2[i];
  }
  motor1.stepsToday = snap.stepsToday1;
  motor2.stepsToday = snap.stepsToday2;
  motor1.totalSteps = snap.totalSteps1;
  motor2.totalSteps = snap.totalSteps2;
  motor1.cyclesCompleted = snap.cycles1;
  motor2.cyclesCompleted = snap.cycles2;
  motor1.smartRotationAccumulator = snap.smartRotAcc1;
  motor2.smartRotationAccumulator = snap.smartRotAcc2;
}

bool readRecordSlot(int slot, PersistRecord& out) {
  EEPROM.get(slotAddress(slot), out);
  if (out.magic != CONFIG_MAGIC || out.version != CONFIG_VERSION || out.valid != RECORD_VALID) return false;
  uint32_t calc = crc32(reinterpret_cast<const uint8_t*>(&out.cfg), sizeof(out.cfg) + sizeof(out.snap));
  return calc == out.crc;
}

void writeRecordSlot(int slot, const PersistRecord& rec) {
  EEPROM.put(slotAddress(slot), rec);
  EEPROM.commit();
}

bool configChanged() {
  if (!hasLastSavedConfig) return true;
  return memcmp(&lastSavedConfig, &config, sizeof(Config)) != 0;
}

void savePersistent(bool forceRuntime) {
  unsigned long now = millis();
  bool shouldWriteConfig = configChanged();
  bool shouldWriteRuntime = forceRuntime || (now - lastPersistMs >= RUNTIME_PERSIST_MS);
  if (!shouldWriteConfig && !shouldWriteRuntime) {
    return;
  }

  PersistRecord rec;
  rec.magic = CONFIG_MAGIC;
  rec.version = CONFIG_VERSION;
  rec.valid = RECORD_VALID;
  rec.seq = ++persistSeq;
  rec.cfg = config;
  captureSnapshot(rec.snap, now);
  rec.crc = crc32(reinterpret_cast<const uint8_t*>(&rec.cfg), sizeof(rec.cfg) + sizeof(rec.snap));

  persistSlot = 1 - persistSlot;
  writeRecordSlot(persistSlot, rec);
  lastSavedConfig = config;
  hasLastSavedConfig = true;
  lastPersistMs = now;
}

void loadPersistent() {
  EEPROM.begin(recordSize() * 2U);
  PersistRecord r0;
  PersistRecord r1;
  bool v0 = readRecordSlot(0, r0);
  bool v1 = readRecordSlot(1, r1);

  if (!v0 && !v1) {
    setDefaultConfig();
    sanitizeConfig();
    dayStartMs = millis();
    savePersistent(true);
    return;
  }

  PersistRecord chosen = r0;
  int chosenSlot = 0;
  if (!v0 || (v1 && r1.seq > r0.seq)) {
    chosen = r1;
    chosenSlot = 1;
  }

  config = chosen.cfg;
  sanitizeConfig();
  applySnapshot(chosen.snap, millis());
  persistSeq = chosen.seq;
  persistSlot = chosenSlot;
  lastSavedConfig = config;
  hasLastSavedConfig = true;
  if (dayStartMs == 0) dayStartMs = millis();
}

bool isHourInRange(int h, int start, int end) {
  if (start <= end) return h >= start && h <= end;
  return h >= start || h <= end;
}

int currentHour(unsigned long now) {
  unsigned long elapsed = now - dayStartMs;
  return (int)((elapsed / HOUR_MS) % 24UL);
}

void resetDailyProgress(unsigned long now) {
  dayStartMs = now;
  hourCursor = 0;
  for (int i = 0; i < 24; i++) {
    hourBuckets1[i] = 0;
    hourBuckets2[i] = 0;
  }
  motor1.stepsToday = 0;
  motor2.stepsToday = 0;
  motor1.cyclesCompleted = 0;
  motor2.cyclesCompleted = 0;
  motor1.smartRotationAccumulator = 0;
  motor2.smartRotationAccumulator = 0;
}

void rollHourlyBuckets(unsigned long now) {
  if (dayStartMs == 0) dayStartMs = now;
  if (now - dayStartMs >= DAY_MS) {
    resetDailyProgress(now);
  }

  int targetHour = currentHour(now);
  while (hourCursor != targetHour) {
    hourCursor = (hourCursor + 1) % 24;
    hourBuckets1[hourCursor] = 0;
    hourBuckets2[hourCursor] = 0;
  }
}

unsigned long targetStepsPerDay(int targetTPD) {
  return (unsigned long)targetTPD * (unsigned long)STEPS_PER_REV;
}

unsigned long speedToDelayMs(int speed) {
  switch (speed) {
    case 1:
      return 7;
    case 2:
      return 6;
    case 3:
      return 5;
    case 4:
      return 4;
    default:
      return 3;
  }
}

bool isQuietHour(unsigned long now) {
  if (!config.quietMode) return false;
  int h = currentHour(now);
  return isHourInRange(h, config.quietStartHour, config.quietEndHour);
}

float driftPercentFor(const MotorRuntime& m, int targetTPD, unsigned long now) {
  unsigned long elapsed = now - dayStartMs;
  if (elapsed == 0) return 0.0f;
  unsigned long targetSteps = targetStepsPerDay(targetTPD);
  float expected = ((float)targetSteps * (float)elapsed) / (float)DAY_MS;
  return ((float)m.stepsToday - expected) * 100.0f / (float)targetSteps;
}

unsigned long computeBurstMs(int targetTPD) {
  int minutes = clampInt(1 + (targetTPD - 500) / 250, 1, 3);
  return (unsigned long)minutes * 60000UL;
}

unsigned long computePauseMs(int targetTPD, float driftPercent) {
  int minutes = clampInt(10 - (targetTPD - 500) / 100, 5, 10);
  if (driftPercent < -3.0f) minutes = max(5, minutes - 2);
  if (driftPercent > 3.0f) minutes = min(10, minutes + 2);
  unsigned long result = (unsigned long)minutes * 60000UL;
  if (result < MIN_PAUSE_MS) result = MIN_PAUSE_MS;
  if (result > MAX_PAUSE_MS) result = MAX_PAUSE_MS;
  return result;
}

unsigned long computeBurstSteps(int targetTPD, float driftPercent) {
  float rotationsPerHour = (float)targetTPD / 24.0f;
  float baseRot = rotationsPerHour / 6.0f;  // roughly every 10 minutes
  float adjust = 1.0f;
  if (driftPercent < -3.0f) adjust = 1.25f;
  if (driftPercent > 3.0f) adjust = 0.8f;
  float rotations = baseRot * adjust;
  unsigned long steps = (unsigned long)(rotations * (float)STEPS_PER_REV);
  unsigned long minSteps = (unsigned long)STEPS_PER_REV / 3UL;
  unsigned long maxSteps = (unsigned long)STEPS_PER_REV * 3UL;
  if (steps < minSteps) steps = minSteps;
  if (steps > maxSteps) steps = maxSteps;
  return steps;
}

bool isMotorActiveHour(const MotorConfig& mc, unsigned long now) {
  return isHourInRange(currentHour(now), mc.activeStartHour, mc.activeEndHour);
}

void stepMotorPhase(int phase, const int pins[4]) {
  digitalWrite(pins[0], seq[phase][0]);
  digitalWrite(pins[1], seq[phase][1]);
  digitalWrite(pins[2], seq[phase][2]);
  digitalWrite(pins[3], seq[phase][3]);
}

void releaseMotor(const int pins[4]) {
  for (int i = 0; i < 4; i++) {
    digitalWrite(pins[i], LOW);
  }
}

void releaseAllMotors() {
  releaseMotor(motorPins1);
  releaseMotor(motorPins2);
}

void setError(ErrorCode code, const char* reason) {
  errorCode = code;
  systemState = SYS_ERROR;
  systemEnabled = false;
  timerActive = false;
  motor1.burstActive = false;
  motor2.burstActive = false;
  releaseAllMotors();
  lastStopReason = reason;
  savePersistent(true);
}

void resetMotorRuntime(MotorRuntime& m, unsigned long now) {
  m.burstActive = false;
  m.burstDirectionCw = true;
  m.nextBidirCw = true;
  m.pauseUntilMs = now;
  m.burstStartMs = 0;
  m.burstTargetSteps = 0;
  m.burstStepsDone = 0;
  m.nextStepAtMs = now;
  m.lastStepMs = now;
  m.phaseIndex = 0;
}

void initRuntimes(unsigned long now) {
  resetMotorRuntime(motor1, now);
  resetMotorRuntime(motor2, now);
}

bool isLagging(float driftPercent) {
  return driftPercent < -3.0f;
}

bool isAhead(float driftPercent) {
  return driftPercent > 3.0f;
}

unsigned long getTimerRemainingMs(unsigned long now) {
  if (!timerActive) return 0;
  if (now >= runUntilMs) return 0;
  return runUntilMs - now;
}

void stopSystem(const char* reason) {
  systemEnabled = false;
  timerActive = false;
  systemState = SYS_IDLE;
  motor1.burstActive = false;
  motor2.burstActive = false;
  releaseAllMotors();
  lastStopReason = reason;
  savePersistent(true);
}

void startSystem(unsigned long now, int minutes) {
  if (errorCode != ERR_NONE) {
    errorCode = ERR_NONE;
  }
  systemEnabled = true;
  systemState = SYS_RUNNING;
  initRuntimes(now);

  if (minutes > 0) {
    timerActive = true;
    runUntilMs = now + (unsigned long)minutes * 60000UL;
  } else {
    timerActive = false;
    runUntilMs = 0;
  }

  lastStopReason = "running";
  savePersistent(true);
}

String activeNetworkMode() {
  return usingApFallback ? "AP" : "STA";
}

String activeIpString() {
  return usingApFallback ? WiFi.softAPIP().toString() : WiFi.localIP().toString();
}

void sendCorsHeaders() {
  server.sendHeader("Access-Control-Allow-Origin", "*");
  server.sendHeader("Access-Control-Allow-Methods", "GET,POST,OPTIONS");
  server.sendHeader("Access-Control-Allow-Headers", "Content-Type");
}

int findJsonKey(const String& body, const char* key) {
  String token = "\"" + String(key) + "\"";
  return body.indexOf(token);
}

bool parseJsonInt(const String& body, const char* key, int& outValue) {
  int keyPos = findJsonKey(body, key);
  if (keyPos < 0) return false;
  int colon = body.indexOf(':', keyPos);
  if (colon < 0) return false;
  int start = colon + 1;
  while (start < body.length() && (body[start] == ' ' || body[start] == '"')) start++;
  int end = start;
  if (end < body.length() && body[end] == '-') end++;
  while (end < body.length() && isDigit(body[end])) end++;
  if (end <= start) return false;
  outValue = body.substring(start, end).toInt();
  return true;
}

bool parseJsonString(const String& body, const char* key, String& outValue) {
  int keyPos = findJsonKey(body, key);
  if (keyPos < 0) return false;
  int colon = body.indexOf(':', keyPos);
  if (colon < 0) return false;
  int q1 = body.indexOf('"', colon + 1);
  if (q1 < 0) return false;
  int q2 = body.indexOf('"', q1 + 1);
  if (q2 < 0) return false;
  outValue = body.substring(q1 + 1, q2);
  return true;
}

bool parseJsonActiveHours(const String& body, int& startHour, int& endHour) {
  int keyPos = findJsonKey(body, "activeHours");
  if (keyPos < 0) return false;
  int b1 = body.indexOf('[', keyPos);
  int b2 = body.indexOf(']', keyPos);
  if (b1 < 0 || b2 < 0 || b2 <= b1) return false;
  String content = body.substring(b1 + 1, b2);
  int comma = content.indexOf(',');
  if (comma < 0) return false;
  startHour = content.substring(0, comma).toInt();
  endHour = content.substring(comma + 1).toInt();
  return true;
}

unsigned long legacyTpdFromGiriDelay(int giri, int delayMin) {
  int fg = clampInt(giri, 1, 10);
  int fd = clampInt(delayMin, 1, 60);
  float tpd = (float)(fg * 2) * (1440.0f / (float)fd);
  return (unsigned long)clampInt((int)(tpd + 0.5f), 500, 1000);
}

void applyMotorConfigFromRequest(MotorConfig& mc, const String& body, const char* suffix) {
  String targetKey = String("targetTPD") + suffix;
  String directionKey = String("direction") + suffix;
  String speedKey = String("speed") + suffix;
  String modeKey = String("mode") + suffix;
  String activeStartKey = String("activeStartHour") + suffix;
  String activeEndKey = String("activeEndHour") + suffix;
  String smartKey = String("smartSwitchRotations") + suffix;

  int v = 0;
  String s;
  if (server.hasArg(targetKey)) mc.targetTPD = clampInt(server.arg(targetKey).toInt(), 500, 1000);
  else if (parseJsonInt(body, targetKey.c_str(), v)) mc.targetTPD = clampInt(v, 500, 1000);

  if (server.hasArg(directionKey)) mc.direction = parseDirection(server.arg(directionKey));
  else if (parseJsonString(body, directionKey.c_str(), s)) mc.direction = parseDirection(s);

  if (server.hasArg(speedKey)) mc.speed = clampInt(server.arg(speedKey).toInt(), 1, 5);
  else if (parseJsonInt(body, speedKey.c_str(), v)) mc.speed = clampInt(v, 1, 5);

  if (server.hasArg(modeKey)) mc.mode = parseMode(server.arg(modeKey));
  else if (parseJsonString(body, modeKey.c_str(), s)) mc.mode = parseMode(s);

  if (server.hasArg(activeStartKey)) mc.activeStartHour = clampInt(server.arg(activeStartKey).toInt(), 0, 23);
  else if (parseJsonInt(body, activeStartKey.c_str(), v)) mc.activeStartHour = clampInt(v, 0, 23);

  if (server.hasArg(activeEndKey)) mc.activeEndHour = clampInt(server.arg(activeEndKey).toInt(), 0, 23);
  else if (parseJsonInt(body, activeEndKey.c_str(), v)) mc.activeEndHour = clampInt(v, 0, 23);

  if (server.hasArg(smartKey)) mc.smartSwitchRotations = clampInt(server.arg(smartKey).toInt(), 2, 100);
  else if (parseJsonInt(body, smartKey.c_str(), v)) mc.smartSwitchRotations = clampInt(v, 2, 100);
}
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
void loop() {
  unsigned long now = millis();

  server.handleClient();
  rollHourlyBuckets(now);

  if (timerActive && now >= runUntilMs) {
    errorCode = ERR_TIMER_DONE;
    systemState = SYS_TIMER_DONE;
    stopSystem("timer_elapsed");
    return;
  }

  if (!systemEnabled) {
    if (systemState != SYS_ERROR && systemState != SYS_TIMER_DONE) {
      systemState = SYS_IDLE;
    }
    savePersistent(false);
    return;
  }

  if (errorCode != ERR_NONE) {
    systemState = SYS_ERROR;
    savePersistent(true);
    return;
  }

  bool needs1 = isMotorActiveHour(config.m1, now) && motor1.stepsToday < targetStepsPerDay(config.m1.targetTPD);
  bool needs2 = isMotorActiveHour(config.m2, now) && motor2.stepsToday < targetStepsPerDay(config.m2.targetTPD);

  if (!needs1 && !needs2) {
    systemState = SYS_PAUSED;
    releaseAllMotors();
    savePersistent(false);
    return;
  }

  systemState = SYS_RUNNING;

  if (activeMotor == 1 && !needs1) activeMotor = 2;
  if (activeMotor == 2 && !needs2) activeMotor = 1;

  bool run1 = activeMotor == 1;
  bool run2 = activeMotor == 2;

  bool active1 = runMotorScheduler(now, motorPins1, config.m1, motor1, run1, true);
  bool active2 = runMotorScheduler(now, motorPins2, config.m2, motor2, run2, false);

  if (activeMotor == 1 && !active1 && needs2) activeMotor = 2;
  if (activeMotor == 2 && !active2 && needs1) activeMotor = 1;

  savePersistent(false);
}
